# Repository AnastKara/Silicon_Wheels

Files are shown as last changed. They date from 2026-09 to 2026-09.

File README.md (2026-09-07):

<div align="center">

# Silicon Wheels

**High-traction cast silicone wheels for mini sumo (500 g) and 3 lb beetleweight combat robots**







**Anastasios Karaivazoglou · IRONBRICK | FIBRAN**

</div>

> [!NOTE]
> **Silicon vs. silicone:** the material used here is **silicone rubber** (a polymer), not the element silicon. "Silicon Wheels" is simply the project name — the tires are cast from platinum-cure silicone.

---

## Table of contents

- [About](#about)
- [Why silicone?](#why-silicone)
- [Features](#features)
- [Specifications](#specifications)
- [Repository layout](#repository-layout)
- [How they are made](#how-they-are-made)
  - [Bill of materials](#bill-of-materials)
  - [Print settings](#print-settings)
  - [Casting procedure](#casting-procedure)
  - [Assembly](#assembly)
- [Mounting to your robot](#mounting-to-your-robot)
- [Tuning & maintenance](#tuning--maintenance)
- [Measured performance](#measured-performance)
- [Troubleshooting](#troubleshooting)
- [FAQ](#faq)
- [Roadmap](#roadmap)
- [Contributing](#contributing)
- [License](#license)
- [Acknowledgments](#acknowledgments)
- [Gallery](#gallery)

## About

Silicon Wheels is a set of open-hardware, high-grip wheels designed from the ground up for two of the most traction-hungry weight classes in hobby robotics:

- **Mini sumo (500 g, 10 × 10 cm footprint)** — where the match is won or lost by static grip and pushing force.
- **3 lb beetleweight combat robots** — where wheels must survive hits, spin-outs, and arena grit while still hooking up under full throttle.

Each wheel is a two-part design: a lightweight **hub** — machined aluminum for mini sumo (JSumo JS2622), printed TPU for the beetleweight — with a keyed outer profile, and a **cast silicone tire** poured directly around it. The silicone locks onto the serrated hub mechanically *and* chemically, so the tire can't spin, slip, or peel off — no adhesives required.

The whole thing is manufacturable on a desktop FDM printer and a workbench: no CNC, no lathe, no special tooling.

## Why silicone?

| Tire option | Grip | Weight | Tunability | Wear life | Cost |
| --- | --- | --- | --- | --- | --- |
| Printed TPU | Medium | Medium | Limited | Good | $ |
| Rubber (FR/Duratrax-style) | High | Medium | None | Medium | $$$ |
| **Cast silicone (this project)** | **Excellent** | **Low** | **Any durometer** | **Good** | **$$** |

- Silicone flows into a mold and cures at room temperature, so **any durometer, diameter, and width is one mold away**.
- Platinum-cure silicones span roughly **Shore 00-30 to 50A**, letting you dial in exactly how soft or durable your contact patch is.
- Cast silicone grips better than printed TPU because there are no layer lines on the tread and the surface stays tough and tacky instead of waxy.

## Features

-  **Zero-slip hub interface** — serrated/keyed hub profile locks the tire mechanically.
-  **Tunable durometer** — swap silicone hardness to match surface and strategy.
-  **Lightweight** — spoked hub keeps rotating mass low for faster acceleration.
-  **Rebuildable** — tires can be recast with minutes of labor; hubs reprint for pennies.
-  **Parameterized** — change a few variables to generate new diameters, widths, and bores.
-  **Drop-in mounting** — sized for common hobby gearmotor shafts (3 mm N20 and 4 mm options).
-  **Two weight classes covered** — geometry validated for mini sumo and 3 lb beetle builds.

## Specifications

<!-- EDIT: Add the as-cast wheel masses when weighed — then delete this comment. -->

| Parameter | Mini sumo wheel | Beetleweight wheel |
| --- | --- | --- |
| Outer diameter | 26.5 mm | 44 mm |
| Tire width | 19 mm silicone (22 mm overall) | 12 mm |
| Hub bore | 3 mm, M4 setscrew tap | 4 mm |
| Hub material | Machined aluminum rim — [JSumo JS2622](https://jsumo.com/js2622-aluminum-silicone-wheel-pair) | TPU, printed rim/hub |
| Tire material | PL30 — 2-part platinum-cure RTV, 1:1 by weight | PL30 — 2-part platinum-cure RTV, 1:1 by weight |
| Tire durometer | ~30 Shore A | ~30 Shore A |
| Wheel mass | 12 g (as-sold JS2622) | — |

## Repository layout

```text
Silicon_Wheels/
├── Combat_Robot_Wheels/            # Beetleweight wheel design & mold
│   ├── Combat_Robot_Silicon_Mold.stl   # Printable two-piece silicone mold
│   ├── Front_Wheel.step            # CAD, front wheel (TPU rim/hub)
│   └── Rear_Wheel.step             # CAD, rear wheel (TPU rim/hub)
├── Mini_Sumo_Wheels/               # Mini sumo (26.5 × 22 mm) mold
│   └── Mini_Sumo_Silicon_Mold.stl  # Printable two-piece silicone mold
├── docs/
│   └── images/                     # Photos used in this README
└── README.md
```

## How they are made

**Process at a glance:**

```text
print mold ──► clean & release ──► mix silicone ──► clamp & pour ──► cure ──► demold & trim ──► mount & test
```

### Bill of materials

| Item | Qty | Price | Notes |
| --- | --- | --- | --- |
| [PL30 platinum-cure silicone — 2×500 g kit](https://www.pacoartcenter.gr/en/platinum-cure-silicone-rubber-compound.html) (Paco Art Center) | 1 kit (1 kg) | €33.90 | Reference tire material — 2-part platinum RTV, mix 1:1 by weight; a wheel pair needs ~40 g, so one kit casts many sets. Bigger kits available up to 2×5 kg (€290). Smooth-On Rebound 25, Sorta-Clear, VytaFlex work as alternatives |
| [Silicone pigment — 25 g](https://www.pacoartcenter.gr/en/crafts/mold-making-casting/mold-making/silicone-pigments.html) (Paco Art Center) | 1 | €3.90 | Optional color. Super-concentrated, platinum-safe: ~10 drops per 100 ml (0.01–3% by weight). Overdosing can inhibit curing or soften the tire — test on a small batch first |
| [JSumo JS2622 aluminum wheel pair](https://jsumo.com/js2622-aluminum-silicone-wheel-pair) | 1 pair | $12.95 | Mini sumo variant — machined rim, 3 mm bore + M4 setscrew; cast PL30 into its 19 mm silicone groove |
| Filament | ~30 g | — | PETG for the mold, TPU 95A for the beetle rim/hub; PLA works for optional rigid hubs |
| [Mold securing screws](https://s.click.aliexpress.com/e/_c2QYYCJZ) + [nuts](https://s.click.aliexpress.com/e/_c2IxNp8B) | 4 + 4 | — | Bolt the two mold halves together — keeps the alignment pins seated and stops silicone leaking along the parting line |
| Mold release agent | 1 | — | Ease Release 200 or equivalent (platinum-safe) |
| [Plastic mixing cups](https://s.click.aliexpress.com/e/_c4EeuXZp) | 2 | — | One for mixing, one for topping off — mix slowly and thoroughly to avoid entrained air |
| [Wooden stir sticks](https://s.click.aliexpress.com/e/_c2xJT4WR) | a few | — | Scrape the walls and bottom of the cup while mixing parts A + B |
| [Digital scale (0.1 g)](https://s.click.aliexpress.com/e/_c34q1PFz) | 1 | — | Required for PL30's 1:1 by-weight mix |
| Nitrile gloves | 1 pair | — | Keep uncured silicone off skin; latex inhibits PL30 |
| Isopropyl alcohol | small bottle | — | Surface prep + cleanup |
| [Carving blades](https://s.click.aliexpress.com/e/_c3cynCwB) | 1 set | — | Trim flash and excess silicone after demolding |
| Vacuum chamber *(optional)* | 1 | — | Bubble-free tires; degassing is strongly recommended |

> [!WARNING]
> **Platinum-cure silicones are inhibition-sensitive.** Uncured SLA resin, sulfur-containing clay, some spray releases, and fresh paint can prevent curing — even latex gloves can poison the cure, so use nitrile or vinyl only. Only use platinum-safe release agents, and if you must mold against an SLA print, wash and post-cure it thoroughly first — FDM molds are the safe default.

### Print settings

**All printed parts are made on a Bambu Lab A1 mini.**

| Part | Material | Layer height | Walls | Infill | Notes |
| --- | --- | --- | --- | --- | --- |
| Hub (rigid, optional) | PETG (PLA works) | 0.16–0.20 mm | 5–6 | 35–45% gyroid | For custom bores / direct drive; strong walls matter for grub-screw clamping |
| Hub (TPU rim) | TPU 95A | 0.20–0.25 mm | 4 | 15–20% | Flexible rim/hub bonds well to cast silicone; print slow |
| Mold | PETG | 0.20 mm | 4 | 20% | Keyed two-piece design prints support-free |

### Casting procedure

1. **Prepare the mold** — clean both halves of the 3D-printed mold thoroughly with isopropyl alcohol, then apply a thin layer of release agent to the inner surfaces (e.g., mold release spray or vaseline). Place the bottom half of the mold on a flat surface and insert the rim (aluminum JS2622 for mini sumo, printed TPU rim for the beetle) — wipe it with IPA first; clean surfaces bond better.
2. **Mix the silicone** — measure 7 g of part A and 7 g of part B into a cup (PL30 mixes 1:1 by weight), add one drop of silicone pigment for color, and mix slowly for 2–3 minutes to avoid bubbles.
3. **Cast the wheel** — carefully place the top mold half and clamp it firmly with the securing screws and nuts. Slowly pour the silicone into the mold until it is completely filled, then let it cure for the recommended time (usually 6–12 hours).
4. **Demold and finish** — once cured, gently open the mold and remove the wheel. Trim any excess silicone (flash) with a carving blade or small scissors.
5. **Mount and test** — mount the silicone wheel on the mini sumo axle (M4 setscrew against the shaft flat) and test grip on the arena surface.

> [!TIP]
> For perfectly bubble-free tires you can degas the mixed silicone in a vacuum chamber for 2–3 minutes before pouring (see the BOM) — slow, thorough mixing already gets you most of the way there.

### Assembly

Because the tire is cast *around* the hub, there is no separate assembly step — the wheel comes out of the mold ready to mount. If you ever need to re-tire a good hub, either:

- **Recast in place:** drop the used hub back into the mold and pour new silicone around it, or
- **Press-fit spare tires:** cast a tire-only puck and press in a freshly printed hub (light interference fit + keying).

## Mounting to your robot

- **3 mm N20-style shafts (mini sumo):** the JSumo JS2622 aluminum rim has a 3 mm bore with an M4 tapped setscrew — clamp on the shaft's flat with a drop of medium threadlocker.
- **4 mm shafts (20 mm+ gearmotors, beetleweight drivetrains):** use the 4 mm bore variant and clamp on the motor's shaft flat.
- Torque the grub screw against the flat, not the shaft diameter, and re-check tightness after your first few hits — impacts back screws out.

## Tuning & maintenance

### Durometer cheat sheet

| Silicone hardness | Character | Best for |
| --- | --- | --- |
| ~00-30 to 20A | Very soft, sticky | Maximum-grip mini sumo, slow pushers |
| ~25–35A | Balanced grip + wear | General mini sumo & beetle drive |
| ~40–50A | Firm, durable | Fast beetles, rough arenas, longer life |

### Care

- **Wipe tires with IPA before every match** — dust and arena grit are grip killers.
- Rotate wheels between matches to even out wear.
- If the tread glazes (shiny, low-grip), a couple of light passes with fine sandpaper restores the surface.
- Store away from UV and direct sunlight to prevent discoloration and slow hardening.

## Measured performance

<!-- EDIT: Pending — fill the µs column after running the pull test below. -->

| Surface | Static friction coefficient (µs, measured) | Notes |
| --- | --- | --- |
| Corian-style sumo board | — | |
| Painted steel arena floor | — | |
| Aluminum weapon arena | — | |

**How to measure µs** (~15 min per surface):

1. Wipe the tires with IPA and let them dry.
2. Weigh the robot in grams (with battery installed).
3. Hook a luggage/fish scale to the rear and pull **horizontally**, increasing force slowly.
4. Record the scale reading at the first slip — wheels start to slide or spin, not roll.
5. µs = pull reading (g) ÷ robot weight (g). Repeat 3× per surface and average.

## Troubleshooting

| Symptom | Likely cause | Fix |
| --- | --- | --- |
| Bubbles in tread | No degassing / poured too fast | Degas the mix; pour thin and high |
| Tire stayed tacky or never cured | Inhibition (resin, wrong release agent, off-ratio mix) | Use platinum-safe release; re-measure the ratio; avoid SLA molds |
| Tire spins on hub | Keying too shallow or oily hub | Wipe hub with IPA before casting; deepen serrations in CAD |
| Wheel wobbles | Mold halves misaligned | Assemble mold with alignment pins fully seated |
| Grip fades after minutes | Tread glazing or heat buildup | Lightly sand; step up one durometer |

## FAQ

**Silicon or silicone?**
Silicone. The name belongs to the project — the tire material is platinum-cure silicone rubber.

**How long do the tires last?**
With 25–35A silicone and IPA cleaning, expect many events in mini sumo. Beetles chew tires faster depending on spin-outs and arena grit. Recasting is cheap, so treat tires as consumables.

**Why not just print TPU?**
TPU is a great start, but layer lines, moisture sensitivity, and a limited durometer range cap its grip. Cast silicone gives a seamless tread and any hardness you want.

**Can I run these on brushless direct drive?**
Yes — generate a hub with your motor's bore and bolt pattern and cast as usual.

**Do they mark the arena?**
Very soft compounds can; 30A and firmer generally don't. Always test on the event's surface first.

## Roadmap

- [ ] Fully parametric OpenSCAD generator (diameter × width × bore, durometer embossed on the hub)
- [ ] 50 mm "max-legal" mini sumo variant
- [ ] Hex-bore hub for direct gearbox output mounting
- [ ] Colored silicone lineup (pigment tests)
- [ ] Traction test jig and published µs dataset

## Contributing

Issues, forks, and PRs are welcome — especially traction data from different arenas. If you build a variant, open an issue with photos plus your print and silicone settings so it can be added to a community builds section.

## License

**All rights reserved.** See [`LICENSE`](LICENSE) for the full notice. The documentation, hardware design files, and images may not be copied, redistributed, or used to create derivative works without prior written permission — reach out if you'd like to build on this project.

## Acknowledgments

- The mini sumo and combat robotics community, for decades of accumulated tire lore.
- Everyone who ever lost a match to a grippier wheel — this project exists because of you.

## Gallery

| Finished beetleweight (combat) wheel | Mini sumo PL30 casts, fresh out of the mold |
| --- | --- |
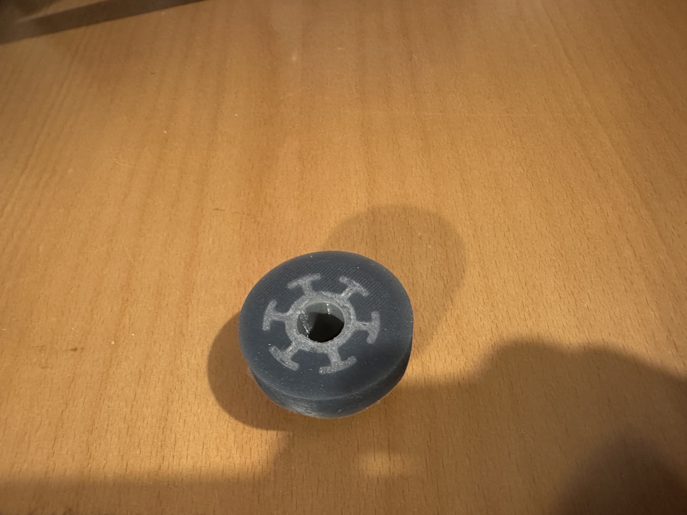
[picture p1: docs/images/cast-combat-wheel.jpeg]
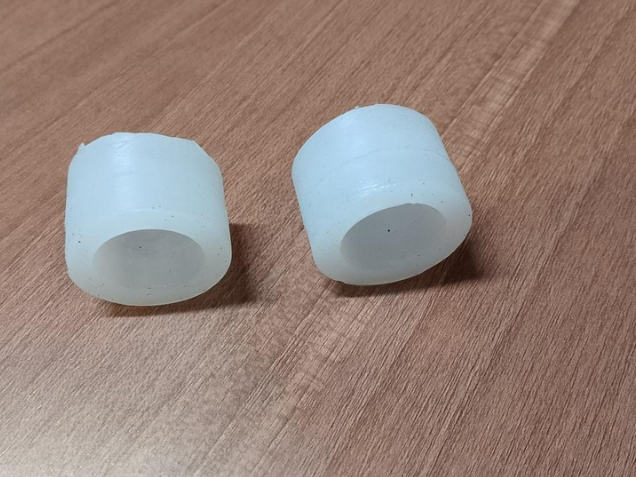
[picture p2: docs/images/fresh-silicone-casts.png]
|  |  |

---

<div align="center">

**Built to hook up.** 

</div>

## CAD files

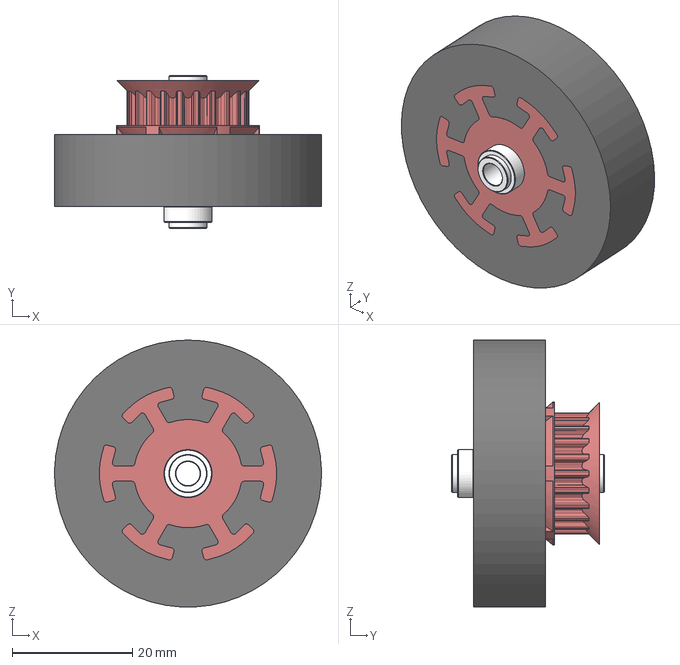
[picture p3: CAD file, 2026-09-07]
Silicon_Wheels/Combat_Robot_Wheels/Front_Wheel.step
44.4 x 25.4 x 44.4 mm
Custom 1in Aluminum Bushing
22t_s3m Wheel

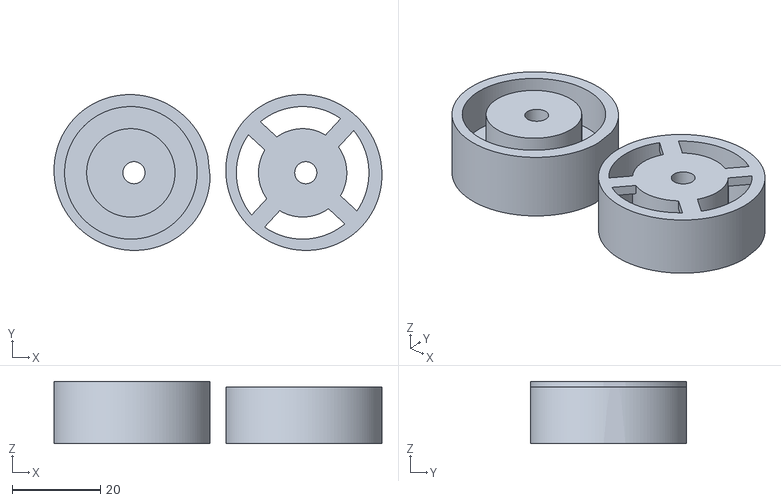
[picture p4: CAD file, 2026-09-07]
Silicon_Wheels/Mini_Sumo_Wheels/Mini_Sumo_Silicon_Mold.stl
74.3 x 35.3 x 14.1

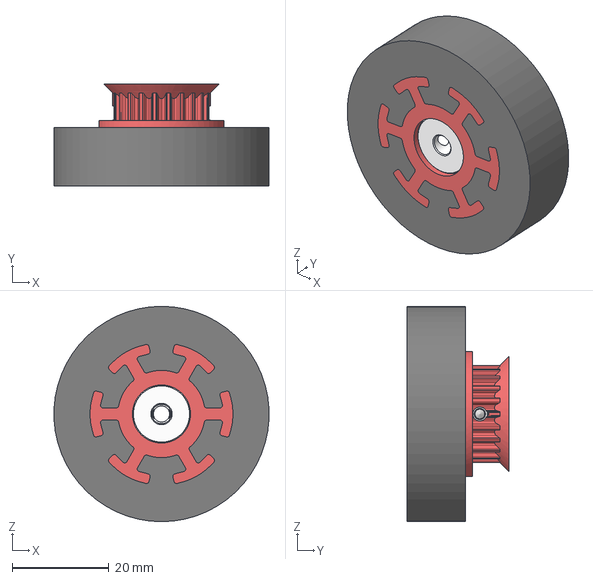
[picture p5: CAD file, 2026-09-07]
Silicon_Wheels/Combat_Robot_Wheels/Rear_Wheel.step
44.4 x 21.0 x 44.4 mm
22t_s3m Wheel
91390A110_Alloy Steel Cup-Point Set Screw x 2

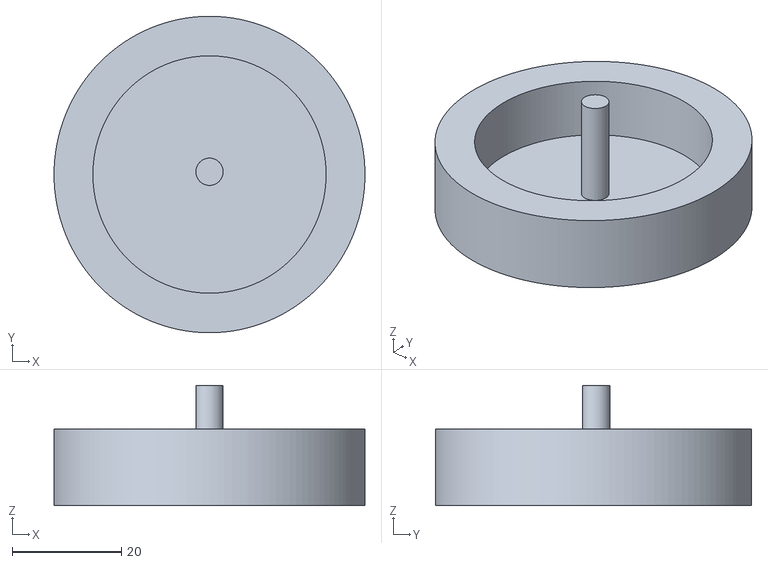
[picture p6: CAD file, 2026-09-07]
Silicon_Wheels/Combat_Robot_Wheels/Combat_Robot_Silicon_Mold.stl
57.0 x 58.0 x 22.0
